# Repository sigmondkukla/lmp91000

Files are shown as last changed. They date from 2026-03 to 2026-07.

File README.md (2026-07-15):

# EFR32BG24 Potentiostat Firmware & Debugger

This repository contains the C++ firmware for the custom potentiostat platform (featuring an LMP91000 analog front end, EFR32BG24 MCU, and an LSM6DSV IMU) alongside a Python-based real-time wireless BLE debugging client.

---

## 1. Prerequisites and Requirements

### Hardware

* Custom Potentiostat PCB (EFR32BG24, LMP91000, LSM6DSV)
* Segger J-Link or Simplicity Link Debugger
* A stable external power source (e.g., 3.3V bench power or a well-charged battery with adequate bulk capacitance)

### Software

* Simplicity Commander (added to your system PATH)
* Python 3.8 or newer
* Bleak Python library (for BLE communications)

---

## 2. Initial Setup (Wired Flashing)

Before the board can accept wireless updates, you must flash the bootloader and the initial application image via a physical JTAG/SWD debug connection.

### Step 1: Flash the Gecko Bootloader

The Gecko Bootloader is responsible for managing internal storage and installing GBL files. You must flash the combined bootloader image containing both the first-stage and main bootloader configurations.

```bash
commander flash bootloader-storage-internal-single-combined.s37 --device EFR32BG24

```

### Step 2: Flash the Application Firmware

Flash the initial C++ application binary:

```bash
commander flash potentiostat_app.s37 --device EFR32BG24

```

---

## 3. Over-The-Air (OTA) Firmware Updates

The custom board supports wireless updates using the Silicon Labs Apploader. When the board reboots into OTA mode, it will advertise as `OTA_potentiostat`.

### OTA Update Steps
#### *Make sure to hold down the power button during the entire OTA upload process, and for about 15-20 seconds after it finishes*

1. Build the firmware project to generate your target `.gbl` file.
2. Put the device into OTA mode. The device will stop regular advertising and begin advertising as `OTA_potentiostat`.
3. Open the **EFR Connect** app on your smartphone or pc.
4. Scan and connect to **OTA_potentiostat**.
5. Select **OTA DFU**, choose **Partial OTA** (or select your `.gbl` file), and initiate the transfer.
6. Upon reaching 100%, the chip will reboot, verify the image, and boot into your new application.

---

## 4. Real-Time Wireless Log Stream

The firmware includes a high-speed wireless logger that routes standard debug prints over a custom BLE characteristic.

### Installation

Install the required asynchronous BLE library:

```bash
pip install bleak

```

### Python Logger Client: `ble_logger.py`

### Usage

1. Power on your potentiostat board.
2. Run the client script:
```bash
python ble_logger.py

```

3. The script will automatically scan, establish a secure BLE connection to your EFR32, subscribe to the notifications, and print custom `ble_printf` debug logs directly to your console.

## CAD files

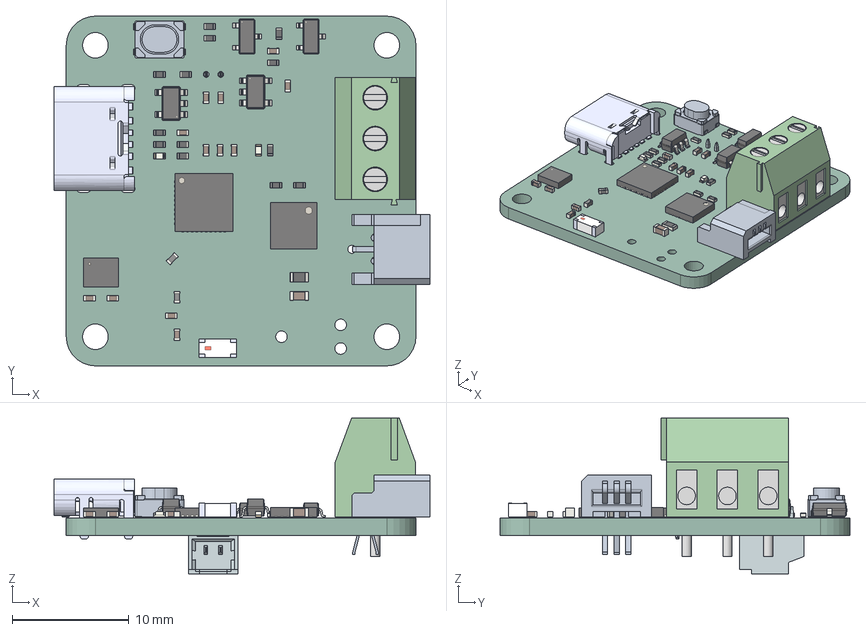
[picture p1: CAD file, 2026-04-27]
pcb/lmp91000-pcb.step
32.3 x 30.0 x 13.4 mm
L_0402_1005Metric x 2
C_0402_1005Metric x 12
kicad_embedded_A8510B68CFC4A96948073CFF479F03DE
R_0402_1005Metric x 13
kicad_embedded_B93A11EA1FA8F882D6A43FACFF969360
LGA-14_3x2.5mm_P0.5mm_LayoutBorder3x4y
SOT-23-5 x 2
PTS815SJM250SMTRLFS_PART1
PTS815SJM250SMTRLFS_PART2
PTS815SJM250SMTRLFS_PART3
SOT-23 x 2
LED_0402_1005Metric x 2
WSON-14-1EP_4.0x4.0mm_P0.5mm_EP2.6x2.6mm
R_0603_1608Metric
kicad_embedded_E5BDF5421597FDD44E6AF183F288C6FF
QFN-40-1EP_5x5mm_P0.4mm_EP3.6x3.6mm
C_0603_1608Metric
kicad_embedded_33D4075191DE50949C470410477CC0A1
lmp91000-pcb_PCB

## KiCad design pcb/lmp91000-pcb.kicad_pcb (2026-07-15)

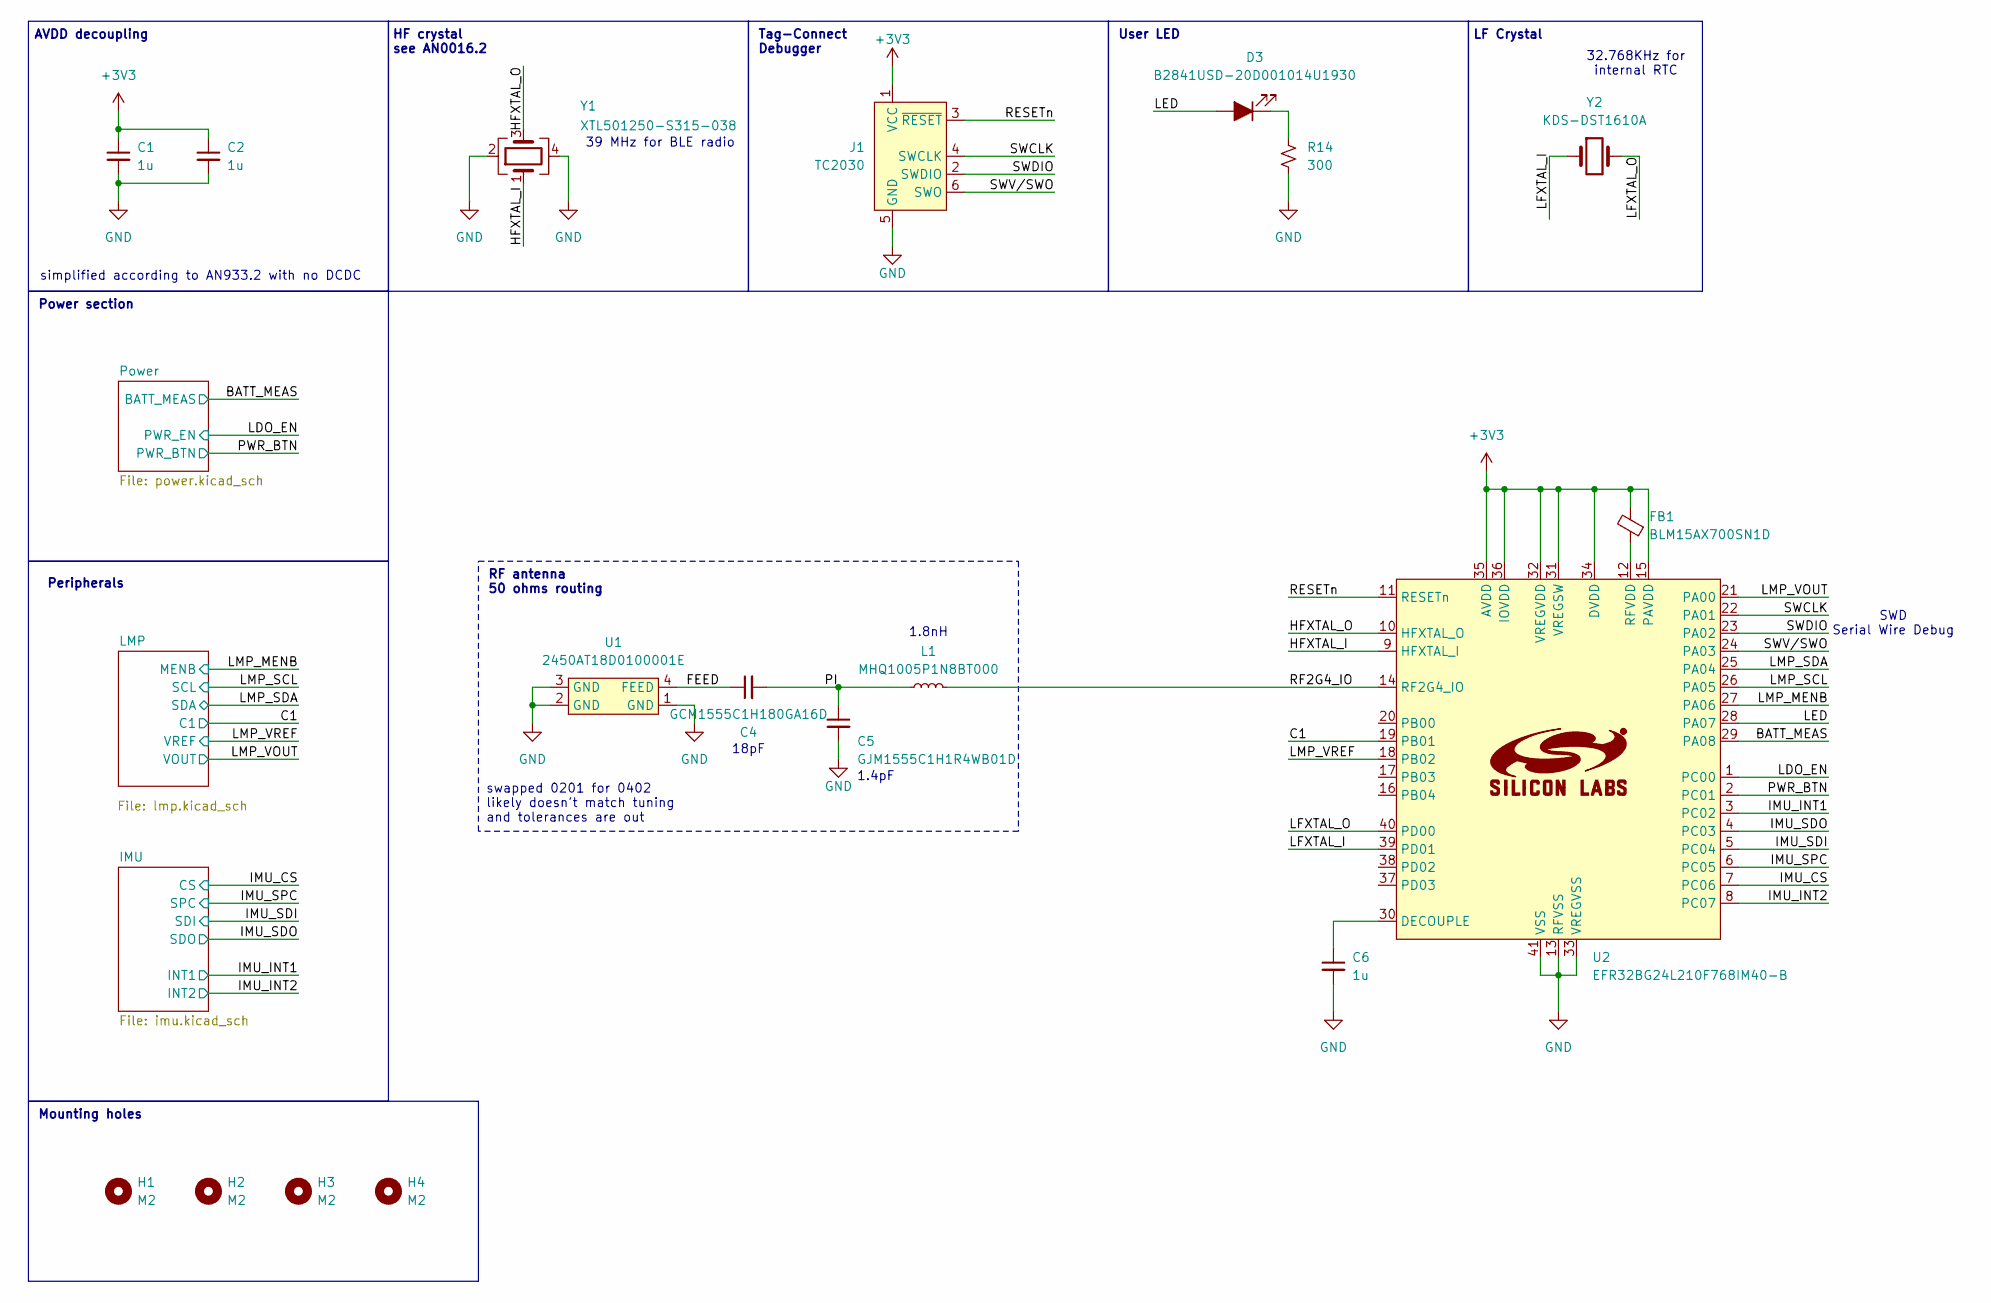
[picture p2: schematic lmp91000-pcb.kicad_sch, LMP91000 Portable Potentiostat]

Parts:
C1, C2, C6: 1u; C_0402_1005Metric
C4: GCM1555C1H180GA16D; C_0402_1005Metric
C5: GJM1555C1H1R4WB01D; C_0402_1005Metric
D3: B2841USD-20D001014U1930; LED_0402_1005Metric
FB1: BLM15AX700SN1D; L_0402_1005Metric
H1, H2, H3, H4: M2; MountingHole_2.2mm_M2
J1: TC2030; Tag-Connect_TC2030-IDC-NL_2x03_P1.27mm_Vertical
L1: MHQ1005P1N8BT000; L_0402_1005Metric
R14: 300; R_0402_1005Metric
U1: 2450AT18D0100001E; Johanson_2450AT18D0100001E
U2: EFR32BG24L210F768IM40-B; QFN-40-1EP_5x5mm_P0.4mm_EP3.8x3.8mm
Y1: XTL501250-S315-038; Crystal_SMD_2016-4Pin_2.0x1.6mm
Y2: KDS-DST1610A

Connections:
+3V3: C1.1, C2.1, FB1.2, J1.1 (VCC), U2.15 (PAVDD), U2.31 (VREGSW), U2.32 (VREGVDD), U2.34 (DVDD), U2.35 (AVDD), U2.36 (IOVDD); also elsewhere on the board
/BATT_MEAS: U2.29 (PA08); also elsewhere on the board
/C1: U2.19 (PB01); also elsewhere on the board
/FEED: C4.1, U1.4 (FEED)
/HFXTAL_I: U2.9 (HFXTAL_I), Y1.1
/HFXTAL_O: U2.10 (HFXTAL_O), Y1.3
/IMU_CS: U2.7 (PC06); also elsewhere on the board
/IMU_INT1: U2.3 (PC02); also elsewhere on the board
/IMU_INT2: U2.8 (PC07); also elsewhere on the board
/IMU_SDI: U2.5 (PC04); also elsewhere on the board
/IMU_SDO: U2.4 (PC03); also elsewhere on the board
/IMU_SPC: U2.6 (PC05); also elsewhere on the board
/LDO_EN: U2.1 (PC00); also elsewhere on the board
/LED: D3.2 (A), U2.28 (PA07)
/LFXTAL_I: U2.39 (PD01), Y2.1
/LFXTAL_O: U2.40 (PD00), Y2.2
/LMP_MENB: U2.27 (PA06); also elsewhere on the board
/LMP_SCL: U2.26 (PA05); also elsewhere on the board
/LMP_SDA: U2.25 (PA04); also elsewhere on the board
/LMP_VOUT: U2.21 (PA00); also elsewhere on the board
/LMP_VREF: U2.18 (PB02); also elsewhere on the board
/PI: C4.2, C5.1, L1.1
/PWR_BTN: U2.2 (PC01); also elsewhere on the board
/RESETn: J1.3 (~RESET), U2.11 (RESETn)
/RF2G4_IO: L1.2, U2.14 (RF2G4_IO)
/SWCLK: J1.4 (SWCLK), U2.22 (PA01)
/SWDIO: J1.2 (SWDIO), U2.23 (PA02)
/SWV/SWO: J1.6 (SWO), U2.24 (PA03)
GND: C1.2, C2.2, C5.2, C6.2, J1.5 (GND), R14.2, U1.1 (GND), U1.2 (GND), U1.3 (GND), U2.13 (RFVSS), U2.33 (VREGVSS), U2.41 (VSS), Y1.2, Y1.4; also elsewhere on the board
unnamed: D3.1 (K), R14.1
unnamed: C6.1, U2.30 (DECOUPLE)
unnamed: FB1.1, U2.12 (RFVDD)

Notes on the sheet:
1.4pF
User LED
Peripherals
1.8nH
32.768KHz for internal RTC
simplified according to AN933.2 with no DCDC
HF crystal see AN0016.2
SWD Serial Wire Debug
RF antenna 50 ohms routing
Tag-Connect Debugger
Mounting holes
39 MHz for BLE radio
LF Crystal
swapped 0201 for 0402 likely doesn't match tuning and tolerances are out
18pF
Power section
AVDD decoupling

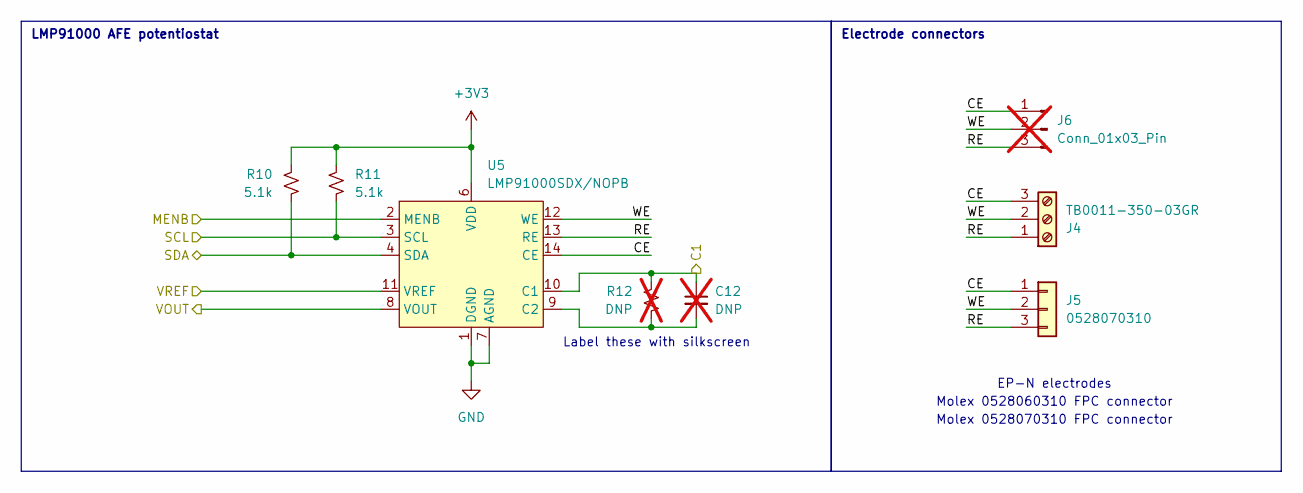
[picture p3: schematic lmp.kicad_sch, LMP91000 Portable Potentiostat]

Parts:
C12: DNP; C_0603_1608Metric_Pad1.08x0.95mm_HandSolder; not fitted
J4: TB0011-350-03GR; SAMESKY_TB0011-350-03GR
J5: 0528070310; 528070310
J6: Conn_01x03_Pin; PinHeader_1x03_P2.54mm_Vertical; not fitted
R10, R11: 5.1k; R_0402_1005Metric
R12: DNP; R_0603_1608Metric_Pad0.98x0.95mm_HandSolder; not fitted
U5: LMP91000SDX/NOPB; WSON-14-1EP_4.0x4.0mm_P0.5mm_EP2.6x2.6mm

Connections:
+3V3: R10.2, R11.2, U5.6 (VDD); also elsewhere on the board
/C1: C12.1, R12.1, U5.10 (C1); also elsewhere on the board
/LMP/CE: J4.3, J5.1, J6.1, U5.14 (CE)
/LMP/RE: J4.1, J5.3, J6.3, U5.13 (RE)
/LMP/WE: J4.2, J5.2, J6.2, U5.12 (WE)
/LMP_MENB: U5.2 (MENB); also elsewhere on the board
/LMP_SCL: R11.1, U5.3 (SCL); also elsewhere on the board
/LMP_SDA: R10.1, U5.4 (SDA); also elsewhere on the board
/LMP_VOUT: U5.8 (VOUT); also elsewhere on the board
/LMP_VREF: U5.11 (VREF); also elsewhere on the board
GND: U5.1 (DGND), U5.7 (AGND), U5.15 (DAP); also elsewhere on the board
unnamed: C12.2, R12.2, U5.9 (C2)

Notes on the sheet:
Label these with silkscreen
Molex 0528070310 FPC connector
EP-N electrodes
Molex 0528060310 FPC connector
LMP91000 AFE potentiostat
Electrode connectors

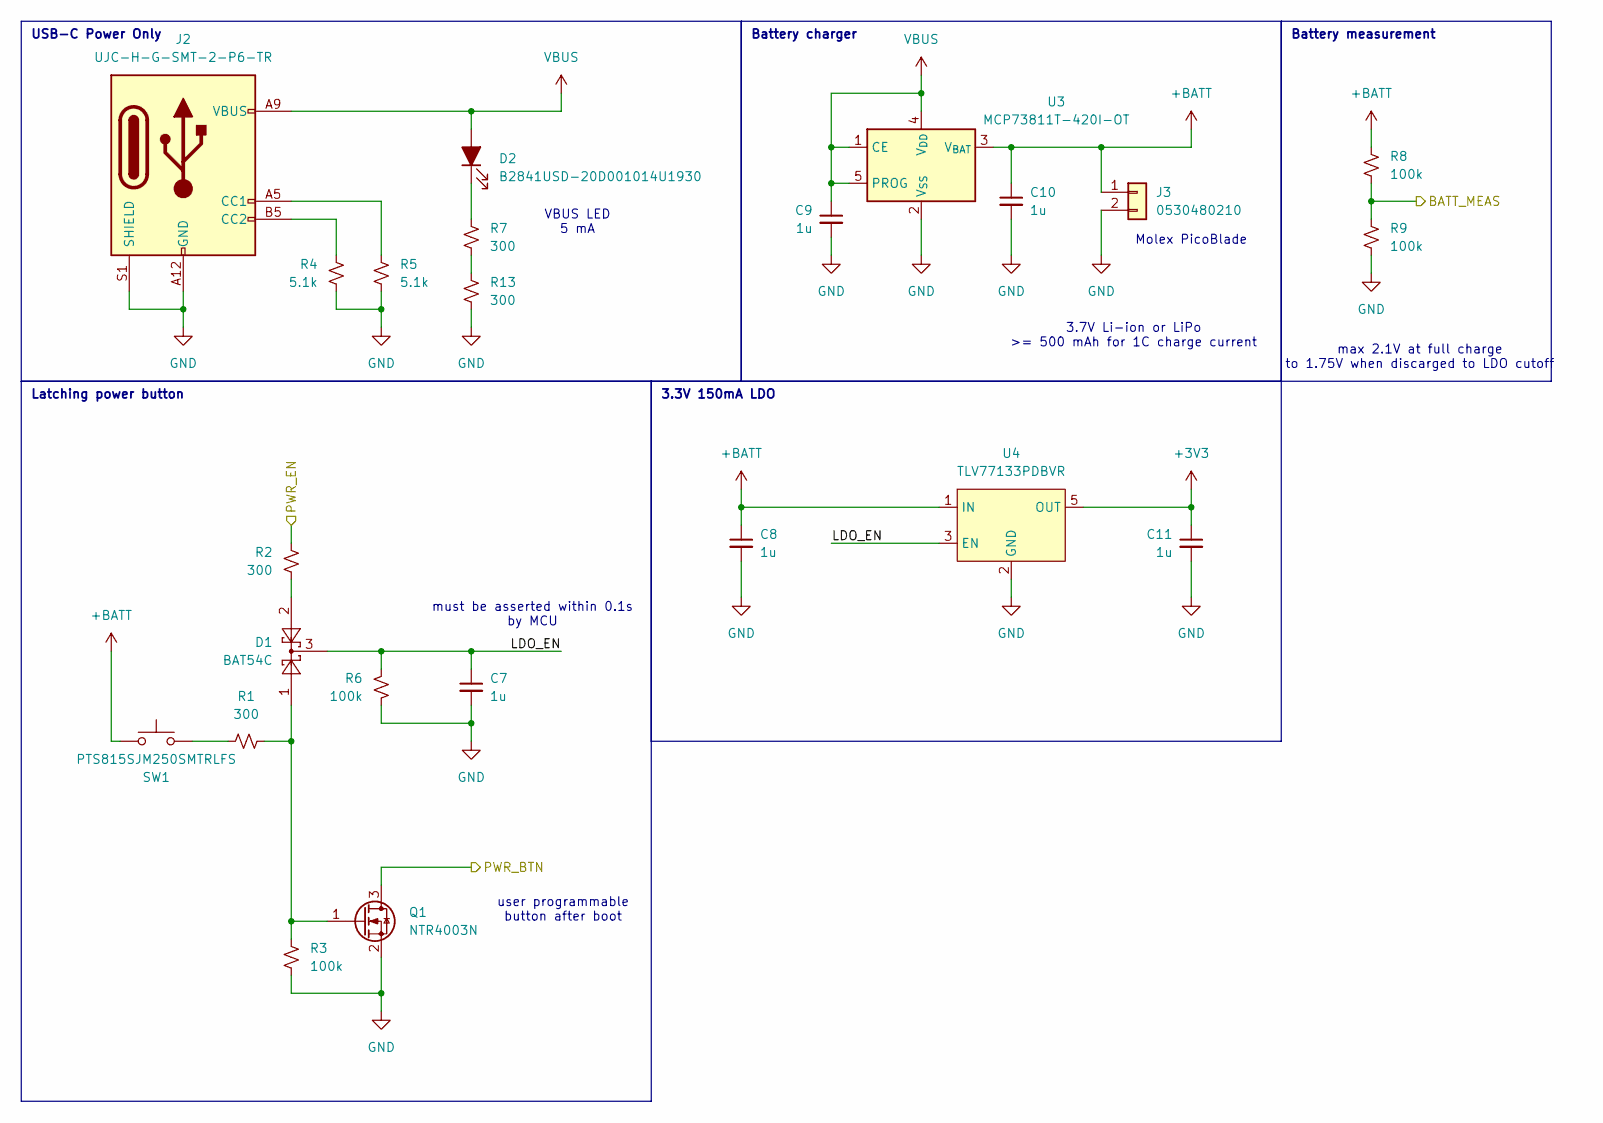
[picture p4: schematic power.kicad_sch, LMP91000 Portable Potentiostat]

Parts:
C7, C8, C9, C10, C11: 1u; C_0402_1005Metric
D1: BAT54C; SOT-23
D2: B2841USD-20D001014U1930; LED_0402_1005Metric
J2: UJC-H-G-SMT-2-P6-TR; SAMESKY_UJC-H-G-SMT-2-P6-TR
J3: 0530480210; Molex_PicoBlade_53048-0210_1x02_P1.25mm_Horizontal
Q1: NTR4003N; SOT-23
R1, R2, R7, R13: 300; R_0402_1005Metric
R3, R6, R8, R9: 100k; R_0402_1005Metric
R4, R5: 5.1k; R_0402_1005Metric
SW1: PTS815SJM250SMTRLFS; SW_Push_PTS815_SJM_250_SMTR_LFS
U3: MCP73811T-420I-OT; SOT-23-5
U4: TLV77133PDBVR; SOT-23-5

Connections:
+3V3: C11.1, U4.5 (OUT); also elsewhere on the board
+BATT: C8.1, C10.1, J3.1, R8.1, SW1.1, U3.3 (V_{BAT}), U4.1 (IN)
/BATT_MEAS: R8.2, R9.1; also elsewhere on the board
/LDO_EN: R2.1; also elsewhere on the board
/PWR_BTN: Q1.3 (D); also elsewhere on the board
/Power/LDO_EN: C7.1, D1.3, R6.1, U4.3 (EN)
GND: C7.2, C8.2, C9.2, C10.2, C11.2, J2.A12 (GND), J2.B12 (GND), J2.S1 (SHIELD), J3.2, Q1.2 (S), R3.2, R4.1, R5.1, R6.2, R9.2, R13.2, U3.2 (V_{SS}), U4.2 (GND), U4.4 (NC); also elsewhere on the board
unnamed: D1.2, R2.2
unnamed: D2.1 (K), R7.1
unnamed: J2.A5 (CC1), R5.2
unnamed: J2.B5 (CC2), R4.2
unnamed: D1.1, Q1.1 (G), R1.2, R3.1
unnamed: R1.1, SW1.2
unnamed: R7.2, R13.1
VBUS: C9.1, D2.2 (A), J2.A9 (VBUS), J2.B9 (VBUS), U3.1 (CE), U3.4 (V_{DD}), U3.5 (PROG)

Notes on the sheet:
USB-C Power Only
must be asserted within 0.1s by MCU
3.7V Li-ion or LiPo >= 500 mAh for 1C charge current
VBUS LED 5 mA
Molex PicoBlade
Battery charger
Battery measurement
Latching power button
3.3V 150mA LDO
user programmable button after boot
max 2.1V at full charge to 1.75V when discarged to LDO cutoff

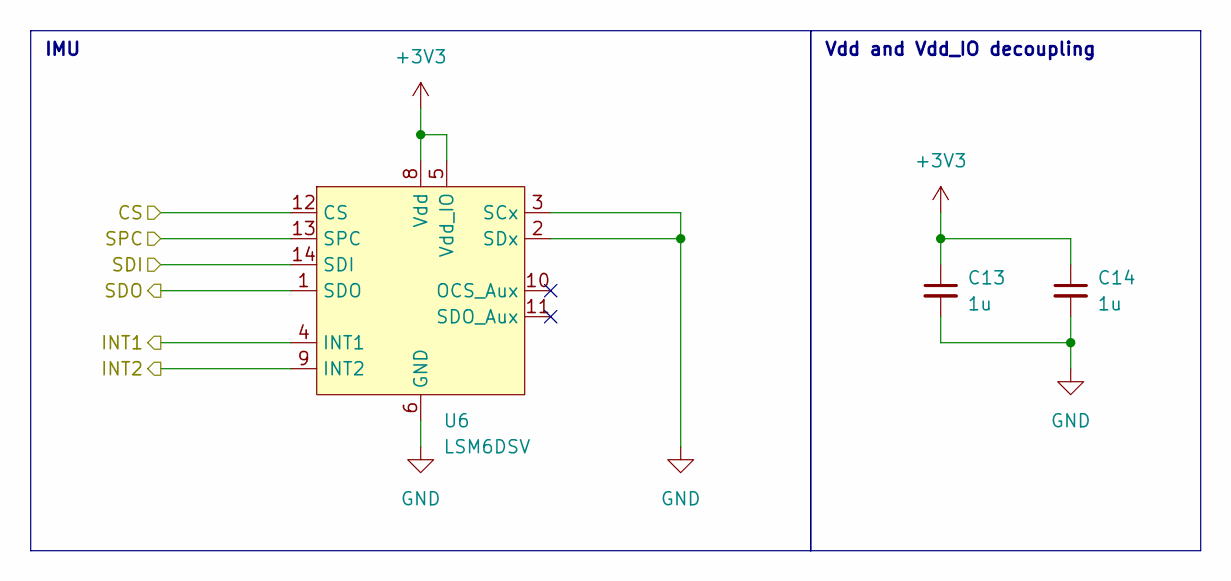
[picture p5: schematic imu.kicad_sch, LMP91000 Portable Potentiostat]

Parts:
C13, C14: 1u; C_0402_1005Metric
U6: LSM6DSV; LGA-14_3x2.5mm_P0.5mm_LayoutBorder3x4y

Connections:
+3V3: C13.1, C14.1, U6.5 (Vdd_IO), U6.8 (Vdd); also elsewhere on the board
/IMU_CS: U6.12 (CS); also elsewhere on the board
/IMU_INT1: U6.4 (INT1); also elsewhere on the board
/IMU_INT2: U6.9 (INT2); also elsewhere on the board
/IMU_SDI: U6.14 (SDI); also elsewhere on the board
/IMU_SDO: U6.1 (SDO); also elsewhere on the board
/IMU_SPC: U6.13 (SPC); also elsewhere on the board
GND: C13.2, C14.2, U6.2 (SDx), U6.3 (SCx), U6.6 (GND), U6.7 (GND); also elsewhere on the board

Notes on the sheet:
IMU
Vdd and Vdd_IO decoupling

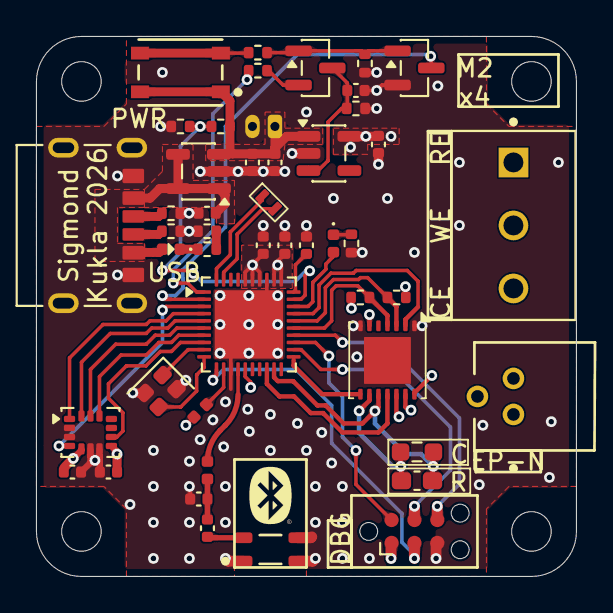
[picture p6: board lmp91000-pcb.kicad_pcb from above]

Board: 4 copper layers, 30.0 x 30.0 mm, 51 parts (1 on the bottom side), 46 nets.

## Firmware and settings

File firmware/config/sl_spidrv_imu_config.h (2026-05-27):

/***************************************************************************//**
 * @file
 * @brief SPIDRV Config
 *******************************************************************************
 * # License
 * <b>Copyright 2019 Silicon Laboratories Inc. www.silabs.com</b>
 *******************************************************************************
 *
 * SPDX-License-Identifier: Zlib
 *
 * The licensor of this software is Silicon Laboratories Inc.
 *
 * This software is provided 'as-is', without any express or implied
 * warranty. In no event will the authors be held liable for any damages
 * arising from the use of this software.
 *
 * Permission is granted to anyone to use this software for any purpose,
 * including commercial applications, and to alter it and redistribute it
 * freely, subject to the following restrictions:
 *
 * 1. The origin of this software must not be misrepresented; you must not
 *    claim that you wrote the original software. If you use this software
 *    in a product, an acknowledgment in the product documentation would be
 *    appreciated but is not required.
 * 2. Altered source versions must be plainly marked as such, and must not be
 *    misrepresented as being the original software.
 * 3. This notice may not be removed or altered from any source distribution.
 *
 ******************************************************************************/

#ifndef SL_SPIDRV_IMU_CONFIG_H
#define SL_SPIDRV_IMU_CONFIG_H

#include "spidrv.h"

// <<< Use Configuration Wizard in Context Menu >>>
// <h> SPIDRV settings

// <o SL_SPIDRV_IMU_BITRATE> SPI bitrate
// <i> Default: 1000000
#define SL_SPIDRV_IMU_BITRATE           1000000

// <o SL_SPIDRV_IMU_FRAME_LENGTH> SPI frame length <4-16>
// <i> Default: 8
#define SL_SPIDRV_IMU_FRAME_LENGTH      8

// <o SL_SPIDRV_IMU_TYPE> SPI mode
// <spidrvMaster=> Master
// <spidrvSlave=> Slave
#define SL_SPIDRV_IMU_TYPE              spidrvMaster

// <o SL_SPIDRV_IMU_BIT_ORDER> Bit order on the SPI bus
// <spidrvBitOrderLsbFirst=> LSB transmitted first
// <spidrvBitOrderMsbFirst=> MSB transmitted first
#define SL_SPIDRV_IMU_BIT_ORDER         spidrvBitOrderMsbFirst

// <o SL_SPIDRV_IMU_CLOCK_MODE> SPI clock mode
// <spidrvClockMode0=> SPI mode 0: CLKPOL=0, CLKPHA=0
// <spidrvClockMode1=> SPI mode 1: CLKPOL=0, CLKPHA=1
// <spidrvClockMode2=> SPI mode 2: CLKPOL=1, CLKPHA=0
// <spidrvClockMode3=> SPI mode 3: CLKPOL=1, CLKPHA=1
#define SL_SPIDRV_IMU_CLOCK_MODE        spidrvClockMode0

// <o SL_SPIDRV_IMU_CS_CONTROL> SPI master chip select (CS) control scheme.
// <spidrvCsControlAuto=> CS controlled by the SPI driver
// <spidrvCsControlApplication=> CS controlled by the application
#define SL_SPIDRV_IMU_CS_CONTROL        spidrvCsControlAuto

// <o SL_SPIDRV_IMU_SLAVE_START_MODE> SPI slave transfer start scheme
// <spidrvSlaveStartImmediate=> Transfer starts immediately
// <spidrvSlaveStartDelayed=> Transfer starts when the bus is idle (CS deasserted)
// <i> Only applies if instance type is spidrvSlave
#define SL_SPIDRV_IMU_SLAVE_START_MODE  spidrvSlaveStartImmediate
// </h>
// <<< end of configuration section >>>

// <<< sl:start pin_tool >>>
// <usart signal=TX,RX,CLK,(CS)> SL_SPIDRV_IMU
// $[USART_SL_SPIDRV_IMU]
#ifndef SL_SPIDRV_IMU_PERIPHERAL                
#define SL_SPIDRV_IMU_PERIPHERAL                 USART0
#endif
#ifndef SL_SPIDRV_IMU_PERIPHERAL_NO             
#define SL_SPIDRV_IMU_PERIPHERAL_NO              0
#endif

// USART0 TX on PC04
#ifndef SL_SPIDRV_IMU_TX_PORT                   
#define SL_SPIDRV_IMU_TX_PORT                    SL_GPIO_PORT_C
#endif
#ifndef SL_SPIDRV_IMU_TX_PIN                    
#define SL_SPIDRV_IMU_TX_PIN                     4
#endif

// USART0 RX on PC03
#ifndef SL_SPIDRV_IMU_RX_PORT                   
#define SL_SPIDRV_IMU_RX_PORT                    SL_GPIO_PORT_C
#endif
#ifndef SL_SPIDRV_IMU_RX_PIN                    
#define SL_SPIDRV_IMU_RX_PIN                     3
#endif

// USART0 CLK on PC05
#ifndef SL_SPIDRV_IMU_CLK_PORT                  
#define SL_SPIDRV_IMU_CLK_PORT                   SL_GPIO_PORT_C
#endif
#ifndef SL_SPIDRV_IMU_CLK_PIN                   
#define SL_SPIDRV_IMU_CLK_PIN                    5
#endif

// USART0 CS on PC06
#ifndef SL_SPIDRV_IMU_CS_PORT                   
#define SL_SPIDRV_IMU_CS_PORT                    SL_GPIO_PORT_C
#endif
#ifndef SL_SPIDRV_IMU_CS_PIN                    
#define SL_SPIDRV_IMU_CS_PIN                     6
#endif
// [USART_SL_SPIDRV_IMU]$
// <<< sl:end pin_tool >>>

#endif // SL_SPIDRV_IMU_CONFIG_H



// [USART_SL_SPIDRV_IMU]$
// <<< sl:end pin_tool >>>

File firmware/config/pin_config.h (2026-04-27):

#ifndef PIN_CONFIG_H
#define PIN_CONFIG_H

// $[CMU]
// [CMU]$

// $[LFXO]
// [LFXO]$

// $[PRS.ASYNCH0]
// [PRS.ASYNCH0]$

// $[PRS.ASYNCH1]
// [PRS.ASYNCH1]$

// $[PRS.ASYNCH2]
// [PRS.ASYNCH2]$

// $[PRS.ASYNCH3]
// [PRS.ASYNCH3]$

// $[PRS.ASYNCH4]
// [PRS.ASYNCH4]$

// $[PRS.ASYNCH5]
// [PRS.ASYNCH5]$

// $[PRS.ASYNCH6]
// [PRS.ASYNCH6]$

// $[PRS.ASYNCH7]
// [PRS.ASYNCH7]$

// $[PRS.ASYNCH8]
// [PRS.ASYNCH8]$

// $[PRS.ASYNCH9]
// [PRS.ASYNCH9]$

// $[PRS.ASYNCH10]
// [PRS.ASYNCH10]$

// $[PRS.ASYNCH11]
// [PRS.ASYNCH11]$

// $[PRS.ASYNCH12]
// [PRS.ASYNCH12]$

// $[PRS.ASYNCH13]
// [PRS.ASYNCH13]$

// $[PRS.ASYNCH14]
// [PRS.ASYNCH14]$

// $[PRS.ASYNCH15]
// [PRS.ASYNCH15]$

// $[PRS.SYNCH0]
// [PRS.SYNCH0]$

// $[PRS.SYNCH1]
// [PRS.SYNCH1]$

// $[PRS.SYNCH2]
// [PRS.SYNCH2]$

// $[PRS.SYNCH3]
// [PRS.SYNCH3]$

// $[GPIO]
// GPIO SWCLK on PA01
#ifndef GPIO_SWCLK_PORT                         
#define GPIO_SWCLK_PORT                          SL_GPIO_PORT_A
#endif
#ifndef GPIO_SWCLK_PIN                          
#define GPIO_SWCLK_PIN                           1
#endif

// GPIO SWDIO on PA02
#ifndef GPIO_SWDIO_PORT                         
#define GPIO_SWDIO_PORT                          SL_GPIO_PORT_A
#endif
#ifndef GPIO_SWDIO_PIN                          
#define GPIO_SWDIO_PIN                           2
#endif

// GPIO SWV on PA03
#ifndef GPIO_SWV_PORT                           
#define GPIO_SWV_PORT                            SL_GPIO_PORT_A
#endif
#ifndef GPIO_SWV_PIN                            
#define GPIO_SWV_PIN                             3
#endif

// [GPIO]$

// $[TIMER0]
// [TIMER0]$

// $[TIMER1]
// [TIMER1]$

// $[TIMER2]
// [TIMER2]$

// $[TIMER3]
// [TIMER3]$

// $[TIMER4]
// [TIMER4]$

// $[USART0]
// USART0 CLK on PC05
#ifndef USART0_CLK_PORT                         
#define USART0_CLK_PORT                          SL_GPIO_PORT_C
#endif
#ifndef USART0_CLK_PIN                          
#define USART0_CLK_PIN                           5
#endif

// USART0 CS on PC06
#ifndef USART0_CS_PORT                          
#define USART0_CS_PORT                           SL_GPIO_PORT_C
#endif
#ifndef USART0_CS_PIN                           
#define USART0_CS_PIN                            6
#endif

// USART0 RX on PC03
#ifndef USART0_RX_PORT                          
#define USART0_RX_PORT                           SL_GPIO_PORT_C
#endif
#ifndef USART0_RX_PIN                           
#define USART0_RX_PIN                            3
#endif

// USART0 TX on PC04
#ifndef USART0_TX_PORT                          
#define USART0_TX_PORT                           SL_GPIO_PORT_C
#endif
#ifndef USART0_TX_PIN                           
#define USART0_TX_PIN                            4
#endif

// [USART0]$

// $[I2C1]
// [I2C1]$

// $[EUSART1]
// [EUSART1]$

// $[KEYSCAN]
// [KEYSCAN]$

// $[LETIMER0]
// [LETIMER0]$

// $[IADC0]
// IADC0 POS on PA00
#ifndef IADC0_POS_PORT                          
#define IADC0_POS_PORT                           SL_GPIO_PORT_A
#endif
#ifndef IADC0_POS_PIN                           
#define IADC0_POS_PIN                            0
#endif

// [IADC0]$

// $[ACMP0]
// [ACMP0]$

// $[ACMP1]
// [ACMP1]$

// $[VDAC0]
// VDAC0 CH0_MAIN_OUT on PB00
#ifndef VDAC0_CH0_MAIN_OUT_PORT                 
#define VDAC0_CH0_MAIN_OUT_PORT                  SL_GPIO_PORT_B
#endif
#ifndef VDAC0_CH0_MAIN_OUT_PIN                  
#define VDAC0_CH0_MAIN_OUT_PIN                   0
#endif

// [VDAC0]$

// $[VDAC1]
// [VDAC1]$

// $[PCNT0]
// [PCNT0]$

// $[HFXO0]
// [HFXO0]$

// $[I2C0]
// I2C0 SCL on PA05
#ifndef I2C0_SCL_PORT                           
#define I2C0_SCL_PORT                            SL_GPIO_PORT_A
#endif
#ifndef I2C0_SCL_PIN                            
#define I2C0_SCL_PIN                             5
#endif

// I2C0 SDA on PA04
#ifndef I2C0_SDA_PORT                           
#define I2C0_SDA_PORT                            SL_GPIO_PORT_A
#endif
#ifndef I2C0_SDA_PIN                            
#define I2C0_SDA_PIN                             4
#endif

// [I2C0]$

// $[EUSART0]
// [EUSART0]$

// $[PTI]
// [PTI]$

// $[MODEM]
// [MODEM]$

// $[CUSTOM_PIN_NAME]
#ifndef LMP_VOUT_PORT                           
#define LMP_VOUT_PORT                            SL_GPIO_PORT_A
#endif
#ifndef LMP_VOUT_PIN                            
#define LMP_VOUT_PIN                             0
#endif

#ifndef LMP_SDA_PORT                            
#define LMP_SDA_PORT                             SL_GPIO_PORT_A
#endif
#ifndef LMP_SDA_PIN                             
#define LMP_SDA_PIN                              4
#endif

#ifndef LMP_SCL_PORT                            
#define LMP_SCL_PORT                             SL_GPIO_PORT_A
#endif
#ifndef LMP_SCL_PIN                             
#define LMP_SCL_PIN                              5
#endif
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

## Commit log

2026-01-21 Initial project commit
    [imu.kicad_sch, lmp.kicad_sch, lmp91000-pcb.kicad_pcb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]
2026-01-21 Update kicad-library-sigmondkukla
2026-01-21 Remove reset button
    [imu.kicad_sch, lmp91000-pcb.kicad_sch]
2026-01-21 Simplify to minimum buck converter components
    [imu.kicad_sch, lmp.kicad_sch, lmp91000-pcb.kicad_sch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]
2026-01-26 Assign footprints, cleanup schematics, start layout
    [imu.kicad_sch, lmp.kicad_sch, lmp91000-pcb.kicad_pcb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]
2026-01-27 Finish PCB
    [lmp.kicad_sch, lmp91000-pcb.kicad_pcb, lmp91000-pcb.kicad_sch]
2026-01-28 Create fabrication files
    [lmp91000-pcb-B_Cu.gbl, lmp91000-pcb-B_Fab.gbr, lmp91000-pcb-B_Mask.gbs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]
2026-01-28 Move antenna and tag connect
    [imu.kicad_sch, lmp.kicad_sch, lmp91000-pcb.kicad_pcb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]
2026-01-28 Shrink PCB page and center on page
    [lmp91000-pcb.kicad_pcb]
2026-01-28 Adjust RF trace grounding
    [lmp91000-pcb.kicad_pcb]
2026-01-28 Cleaned up routing
    [lmp91000-pcb.kicad_pcb]
2026-01-28 Run DRC
    [lmp91000-pcb.kicad_pcb]
2026-01-28 Remove old production files
    [lmp91000-pcb-B_Cu.gbl, lmp91000-pcb-B_Fab.gbr, lmp91000-pcb-B_Mask.gbs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]
2026-01-28 Update back silkscreen with labels
    [lmp91000-pcb.kicad_pcb]
2026-03-23 Create Simplicity Studio 6 firmware project
    [lmp.kicad_sch, lmp91000-pcb-EMS.kicad_pcb, lmp91000-pcb.kicad_pcb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]
2026-04-06 Update pin config
2026-04-06 Use I2C ports and pins for initialization
2026-04-06 Update ADC
2026-04-06 Switch from SPI DAC to on-chip VDAC
2026-04-08 Change angle brackets to quotes for experiment header includes
2026-04-17 function signitures and SPI testing
2026-04-22 Abstract battery voltage function into separate implementation
2026-04-23 Fixed battery read function and added float linker flag
    [app.cpp]
2026-04-23 implementation for all getters and expample print code
2026-05-07 Fix i2c for new board design
    [app.cpp, lmp91000.h]
2026-06-01 status configuration working with apply button
2026-06-04 removed all printf debug messages
2026-06-05 assert power button pin
2026-06-05 power indicator led
2026-06-11 preventing i2c flooding by only changing bias settings when necessary, added debug prints for BLE notifications and experiment ticks. this allows bluetooth to send live notifications more reliably.
    [lmp91000.h]
2026-06-15 reset previous values after experiment end, experiments now work back to back!
    [lmp91000.h]
2026-06-18 added new output voltage function for CV, DPV, SWV
2026-06-18 make vref change based on current DAC output, (should fix shifting error)
    [app.cpp, lmp91000.h]
2026-07-02 add output voltage test (bad CV works)
2026-07-02 better accounting for current zero
2026-07-14 over the air updates
    [app_ota_dfu.xml]
2026-07-14 add c1 and int1 to pcb
    [imu.kicad_sch, lmp.kicad_sch, lmp91000-pcb.kicad_pcb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]
2026-07-15 Redesign for board order. add LFXO and shield electrode traces better
    [imu.kicad_sch, lmp.kicad_sch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]
